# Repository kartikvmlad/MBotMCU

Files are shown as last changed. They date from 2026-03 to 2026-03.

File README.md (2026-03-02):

# Astra Robotics Controller (ARC-2040)

  

**A high-performance embedded control board designed for autonomous mobile robotics.**

The **Astra Robotics Controller** bridges the gap between prototyping boards and industrial PLCs. Built around the Raspberry Pi **RP2040** microcontroller, it integrates high-current motor drivers, redundant sensing, and non-volatile "Black Box" data logging into a unified, vibration-resistant PCB.

-> To view the schematic, download the repository and open the file **MBot.kicad_sch** in KiCad 

---

## 📋 Table of Contents
- [System Architecture](#-system-architecture)
- [Technical Specifications](#-technical-specifications)
- [Pin Configuration](#-pin-configuration)
- [Power System & Safety](#-power-system--safety)
- [Fabrication Notes](#-fabrication-notes-bom-criticals)
- [Getting Started](#-getting-started)

---

## 🏗 System Architecture

The board is divided into four isolated subsystems to minimize noise and maximize reliability:

1.  **Core Logic:** RP2040 Dual-Core Cortex-M0+ running at 133MHz with 2MB QSPI Flash.
2.  **Actuation:** Dual **DRV8876** H-Bridge drivers capable of 5A peak current, featuring hardware current regulation and fault feedback.
3.  **Sensing:**
    * **Motion:** InvenSense **MPU-9150** (9-DoF IMU) for heading and stabilization.
    * **Environment:** Bosch **BMP280** for barometric altitude and temperature.
    * **Data Logging:** Cypress **FM24W256 F-RAM** for high-speed, infinite-endurance telemetry logging.
4.  **Power:** A hybrid 12V $\to$ 6.5V $\to$ 5V/3.3V power tree using a high-efficiency **XL4015** Buck Converter.

---

## ⚙ Technical Specifications

| Feature | Specification |
| :--- | :--- |
| **Microcontroller** | Raspberry Pi RP2040 (Dual Core ARM M0+ @ 133MHz) |
| **Input Voltage** | 10V - 14V DC (Optimized for 3S LiPo or 12V Lead Acid) |
| **Motor Drive Output** | 2x Channels, 6.5V Regulated @ 3A Continuous / 5A Peak |
| **Logic Voltage** | 3.3V (System) / 5.0V (Auxiliary) |
| **IMU** | MPU-9150 (Gyro + Accel + Mag) via I2C `0x68` |
| **Altimeter** | BMP280 via I2C `0x76` |
| **Non-Volatile Memory** | 256 Kbit (32KB) Ferroelectric RAM via I2C `0x50` |
| **Expansion** | 4x ADC, 2x UART, 1x I2C, 1x SPI |

---

## 📍 Pin Configuration

### External Interfaces
| Port Label | Function | Pinout | Voltage Level |
| :--- | :--- | :--- | :--- |
| **J1 (SWD)** | Firmware Debugging | SWDIO, SWCLK, GND | 3.3V |
| **J3 (ADC)** | Analog Sensors | ADC0-2, 3V3, AGND | 3.3V |
| **J7 (UART0)** | GPS / Lidar | TX, RX, 3V3, GND | 3.3V |
| **J8 (I2C)** | Expansion / OLED | SDA, SCL, 3V3, GND | 3.3V |
| **J14 (PWM)** | Servo / GPIO | PWM_A, PWM_B, 3V3, GND | 3.3V |

### Onboard Switch Multiplexer
The board features hardware toggle switches to route the RP2040 ADC lines:
* **Position A (Left):** ADC monitors **Motor Current** (via DRV8876 IPROPI).
* **Position B (Right):** ADC monitors **External Sensors** (via Port J3).

---

## ⚡ Power System & Safety

This board implements a **Split-Rail Architecture**:
* **VMOT (6.5V Rail):** Powered by an XL4015 Buck Converter. Dedicated to Motors and High-Torque Servos.
* **VSYS (5.0V Rail):** Powered by an AMS1117-5.0. Dedicated to logic-level conversion.
* **3V3 (Logic Rail):** Powered by onboard LDO for MCU and Sensors.

**Safety Features:**
* **Reverse Polarity Protection:** 5A Schottky Diodes on input.
* **Over-Current Protection:** On-board Fuse (F1) and software-readable Current Sense.
* **Thermal Protection:** DRV8876 drivers have automatic thermal shutdown with LED indication (`nFAULT`).

> **⚠️ Usage Warning:** Port `J8`, `J9`, and `J10` (Motor/Aux) supply **6.5V** on Pin 3. Do not connect standard 5V-intolerant logic devices to this pin without checking datasheets.

---

## 🛠 Fabrication Notes (BOM Criticals)

If fabricating this board from the provided Gerbers, strictly adhere to the following component requirements to ensure power stability:

1.  **Diodes (D4, D5, D6):** MUST be **SS54** (5 Amp) or **MBRD1045** (10 Amp). Using SS34 (3A) may result in thermal failure under load.
2.  **Inductor (L1):** Footprint requires a **Shielded Power Inductor** (e.g., CDRH127) rated for **Isat > 5A**.
3.  **Capacitors:**
    * **Cout1:** 330µF/25V Electrolytic Low-ESR is mandatory for 6.5V rail stability.

---

## 🚀 Getting Started

1.  **Hardware Setup:**
    * Connect a 12V battery to the Screw Terminal (J3) or Barrel Jack (J2).
    * Connect motors to the JST outputs `M0` and `M1`.
2.  **Firmware Upload:**
    * Hold the **BOOT** button (or short `BOOTSEL` jumper).
    * Connect USB-C to a PC.
    * Copy your `.uf2` file to the `RPI-RP2` drive.
3.  **Software Addresses:**
    * `BMP280`: **0x76**
    * `MPU9150`: **0x68**
    * `FRAM`: **0x50**

---

**Project Lead:** Kartik Lad  
**Organization:** Astra Robotics  
**License:** Open Source Hardware

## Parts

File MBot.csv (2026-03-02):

Reference | Qty | Value | Cost (per piece) | Total Comp cost | Site | Link to buy | Footprint | Datasheet
C1,C14,C101,C104,C117 | 5 | 10u | ? 1.34 | ? 6.70 | Robu | https://robu.in/product/0805x106k250nt-fh-25v-10uf-x5r%c2%b110-0805-multilayer-ceramic-capacitors-mlcc-smd-smt-rohs/ | Capacitor_SMD:C_0805_2012Metric_Pad1.18x1.45mm_HandSolder | ~
C2,C5,C7 | 3 | 22n | ? 0.68 | ? 2.04 | Robu | https://robu.in/product/22nf-0603-surface-mount-multilayer-ceramic-capacitor-pack-of-50/ | Capacitor_SMD:C_0603_1608Metric_Pad1.08x0.95mm_HandSolder | ~
C3,C4,C6,C13 | 4 | 220n | ? 0.60 | ? 2.40 | Robu | https://robu.in/product/220nf-0603-surface-mount-multilayer-ceramic-capacitor-pack-of-40/ | Capacitor_SMD:C_0603_1608Metric_Pad1.08x0.95mm_HandSolder | ~
C8,C22,C23 | 3 | 10n | ? 0.63 | ? 1.89 | Robu | https://robu.in/product/10nf-0603-surface-mount-multilayer-ceramic-capacitor-pack-of-50/ | Capacitor_SMD:C_0603_1608Metric_Pad1.08x0.95mm_HandSolder | ~
C9,C10,C11,C15,C16,C18,C19,C20,C105,C106,C107,C109,C110,C111,C112,C113,C114,C115,C120 | 19 | 100n | ? 0.30 | ? 5.70 | Robu | https://robu.in/product/100nf-0603-surface-mount-multilayer-ceramic-capacitor-pack-of-40/ | Capacitor_SMD:C_0603_1608Metric_Pad1.08x0.95mm_HandSolder | ~
C12 | 1 | 2.2n | ? 0.42 | ? 0.42 | Robu | https://robu.in/product/2-2nf-0603-surface-mount-multilayer-ceramic-capacitor-pack-of-50/ | Capacitor_SMD:C_0603_1608Metric_Pad1.08x0.95mm_HandSolder | ~
C17 | 1 | 100u |  | ? 0.00 |  |  | Capacitor_SMD:C_0805_2012Metric_Pad1.18x1.45mm_HandSolder | ~
C21,C108 | 2 | 1u | ? 0.55 | ? 1.10 | Robu | https://robu.in/product/0603b105k160nt-fh-16v-1uf-x7r%c2%b110-0603-multilayer-ceramic-capacitors-mlcc-smd-smt-rohs/ | Capacitor_SMD:C_0603_1608Metric_Pad1.08x0.95mm_HandSolder | ~
C102,C103 | 2 | 15p | ? 0.24 | ? 0.48 | Robu | https://robu.in/product/ac0603jrnpo9bn150-yageo-cap-ceramic-15pf-50v-c0g-5-pad-smd-0603-125c-automotive-aec-q200-t-r/ | Capacitor_SMD:C_0603_1608Metric_Pad1.08x0.95mm_HandSolder | ~
CFF1 | 1 | 33n | ? 0.68 | ? 0.68 | Robu | https://robu.in/product/33nf-0603-surface-mount-multilayer-ceramic-capacitor-pack-of-50/ | Capacitor_SMD:C_0603_1608Metric_Pad1.08x0.95mm_HandSolder | ~
Cin1 | 1 | 220u |  | ? 0.00 |  |  | Capacitor_SMD:C_0805_2012Metric_Pad1.18x1.45mm_HandSolder | ~
Cout1,Cout2 | 2 | 22u |  | ? 0.00 |  |  | Capacitor_SMD:C_0805_2012Metric_Pad1.18x1.45mm_HandSolder | ~
D1,D2,D3 | 3 | LED | ? 1.18 | ? 3.54 | Robu | https://robu.in/product/0805-surface-mount-led-red-50-pcs/ | LED_SMD:LED_0805_2012Metric_Pad1.15x1.40mm_HandSolder | ~
D4,D5 | 2 | SS54B | ? 6.00 | ? 12.00 | Robu | https://robu.in/product/ss54b-slkor-40v-550mv5a-5a-smbdo-214aa-schottky-diodes-rohs/ | SS54B:DIOM4336X244N
D6,D7,D8 | 3 | WS2812B-2020 | ? 8.00 | ? 24.00 | Robu | https://robu.in/product/sme-ws2812b-2020-addressable-rgb-pixel-led-worldsemi/ | LED_SMD:LED_WS2812B-2020_PLCC4_2.0x2.0mm | https://cdn-shop.adafruit.com/product-files/4684/4684_WS2812B-2020_V1.3_EN.pdf
D101,D102 | 2 | SS14 | ? 1.35 | ? 2.70 | Robu | https://robu.in/product/ss14-slkor-40v-550mv1a-1a-smado-214ac-schottky-diodes-rohs/ | Diode_SMD:D_SMA_Handsoldering | https://www.vishay.com/docs/88746/ss12.pdf
F1 | 1 | Fuse | ? 33.00 | ? 33.00 | Robu | https://robu.in/product/01550900m-littelfuse-smd5-0x9-7mm-fuseholders-rohs/ | Fuse:Fuse_Littelfuse-NANO2-451_453 | ~
FB1 | 1 | FerriteBead | ? 4.67 | ? 4.67 | Robu | https://robu.in/product/blm21bb201sn1d-murata-ferrite-bead-0805-2012-metric-200-ohm-500-ma-blm21b-0-26-ohm-%c2%b1-25/ | Inductor_SMD:L_0805_2012Metric_Pad1.05x1.20mm_HandSolder | ~
J1 | 1 | Micro_SD_Card_Det1 |  | ? 0.00 |  |  | Connector_Card:microSD_HC_Hirose_DM3AT-SF-PEJM5 | https://datasheet.lcsc.com/lcsc/2110151630_XKB-Connectivity-XKTF-015-N_C381082.pdf
J2 | 1 | Barrel_Jack_Switch_Pin3Ring |  | ? 0.00 |  |  | Connector_BarrelJack:BarrelJack_Horizontal | ~
J3,J5,J6,J7 | 4 | Screw_Terminal_01x02 |  | ? 0.00 |  |  | TerminalBlock_Phoenix:TerminalBlock_Phoenix_MPT-0,5-2-2.54_1x02_P2.54mm_Horizontal | ~
J4 | 1 | Conn_01x03 |  | ? 0.00 |  |  | Connector_JST:JST_VH_B3P-VH_1x03_P3.96mm_Vertical | ~
J8,J9,J10,J12,J13,J14,J15,J17 | 8 | Conn_01x04 |  | ? 0.00 |  |  | Connector_JST:JST_ZH_B4B-ZR_1x04_P1.50mm_Vertical | ~
J11 | 1 | Conn_02x06_Odd_Even |  | ? 0.00 |  |  | Connector_IDC:IDC-Header_2x06_P2.54mm_Vertical | ~
J16 | 1 | Conn_01x06 |  | ? 0.00 |  |  | Connector_JST:JST_ZH_B6B-ZR_1x06_P1.50mm_Vertical | ~
JUSBC1 | 1 | USB_C_Receptacle_USB2.0_16P |  | ? 0.00 |  |  | Connector_USB:USB_C_Receptacle_GCT_USB4085 | https://www.usb.org/sites/default/files/documents/usb_type-c.zip
L1 | 1 | 3.3u | ? 11.00 | ? 11.00 | Robu | https://robu.in/product/srp7050ta-3r3m-bourns-power-inductor-smd-3-3-%c2%b5h-8-a-shielded-12-a/ | Inductor_SMD:L_Bourns_SRP7028A_7.3x6.6mm | ~
R1 | 1 | 100k | ? 1.38 | ? 1.38 | Robu | https://robu.in/product/aa0603jr-07100kl-yageo-100mw-thick-film-resistors-75v-%c2%b15-%c2%b1150ppm-%e2%84%83-100k%cf%89-0603-chip-resistor-surface-mount-rohs/ | Resistor_SMD:R_0603_1608Metric_Pad0.98x0.95mm_HandSolder | ~
R2,R5,R7,R9,R12,R14,R101,R105 | 8 | 1k | ? 0.35 | ? 2.80 | Robu |  | Resistor_SMD:R_0603_1608Metric_Pad0.98x0.95mm_HandSolder | ~
R3,R8,R13,R32,R901 | 5 | 10k | ? 0.35 | ? 1.75 | Robu |  | Resistor_SMD:R_0603_1608Metric_Pad0.98x0.95mm_HandSolder | ~
R4,R11,R16 | 3 | 220 | ? 0.35 | ? 1.05 | Robu |  | Resistor_SMD:R_0603_1608Metric_Pad0.98x0.95mm_HandSolder | ~
R6,R10,R15 | 3 | 20k | ? 0.30 | ? 0.90 | Robu |  | Resistor_SMD:R_0603_1608Metric_Pad0.98x0.95mm_HandSolder | ~
R17,R18,R19 | 3 | 330 | ? 0.46 | ? 1.38 | Robu |  | Resistor_SMD:R_0603_1608Metric_Pad0.98x0.95mm_HandSolder | ~
R23,R24 | 2 | 4.7k | ? 0.35 | ? 0.70 | Robu |  | Resistor_SMD:R_0603_1608Metric_Pad0.98x0.95mm_HandSolder | ~
R27 | 1 | 47k | ? 0.35 | ? 0.35 | Robu |  | Resistor_SMD:R_0603_1608Metric_Pad0.98x0.95mm_HandSolder | ~
R109,RUSB1 | 2 | 5.1k | ? 0.32 | ? 0.64 | Robu |  | Resistor_SMD:R_0603_1608Metric_Pad0.98x0.95mm_HandSolder | ~
R902 | 1 | 75k | ? 0.44 | ? 0.44 | Robu |  | Resistor_SMD:R_0603_1608Metric_Pad0.98x0.95mm_HandSolder | ~
RDminus1,RDplus1 | 2 | 27 | ? 0.82 | ? 1.64 | Robu |  | Resistor_SMD:R_0603_1608Metric_Pad0.98x0.95mm_HandSolder | ~ | 0805 only
SW4,SWRESET1 | 2 | SW_SPST |  | ? 0.00 |  |  | Button_Switch_SMD:SW_Push_SPST_NO_Alps_SKRK | ~
U1 | 1 | 74AUC1G19 | ? 16.00 | ? 16.00 | Robu |  | Package_TO_SOT_SMD:SOT-23-6_Handsoldering | http://www.ti.com/lit/sg/scyt129e/scyt129e.pdf
U2 | 1 | TPS565201DDCR | ? 11.00 | ? 11.00 | Robu |  | TPS565201DDCR:SOT95P280X110-6N |  | sus looking robu
U3 | 1 | FM24W256 | ? 207.00 | ? 207.00 | Robu |  | Package_SO:SOIC-8_3.9x4.9mm_P1.27mm | http://www.cypress.com/file/41651/download
U4 | 1 | TMUX1574PW | ? 37.00 | ? 37.00 | Robu |  | Package_SO:TSSOP-16_4.4x5mm_P0.65mm | https://www.ti.com/lit/ds/symlink/tmux1574.pdf
UBarometer1 | 1 | BMP280 | ? 33.00 | ? 33.00 |  |  | Package_LGA:Bosch_LGA-8_2x2.5mm_P0.65mm_ClockwisePinNumbering | https://ae-bst.resource.bosch.com/media/_tech/media/datasheets/BST-BMP280-DS001.pdf | header pins needed
UDRV1,UDRV2,UDRV3 | 3 | DRV8876PWPR | ? 189.00 | ? 567.00 | Lion Ckt | https://www.lioncircuits.com/parts/DRV8876PWPR | DRV8876PWPR:IC_DRV8876PWPR
UESD1 | 1 | USBLC6-2SC6 | ? 6.00 | ? 6.00 | Robu |  | Package_TO_SOT_SMD:SOT-23-6 | https://www.st.com/resource/en/datasheet/usblc6-2.pdf
UFlashMem1 | 1 | W25Q16JVSS | ? 51.00 | ? 51.00 | Robu |  | Package_SO:SOIC-8_5.3x5.3mm_P1.27mm | https://www.winbond.com/hq/support/documentation/levelOne.jsp?__locale=en&DocNo=DA00-W25Q16JV.1
UIMU1 | 1 | MPU-9150 |  | ? 0.00 | Robu |  | Sensor_Motion:InvenSense_QFN-24_4x4mm_P0.5mm | https://www.invensense.com/wp-content/uploads/2015/02/MPU-9150-Datasheet.pdf
ULDO1 | 1 | NCP1117-3.3_SOT223 | ? 23.00 | ? 23.00 | Robu |  | Package_TO_SOT_SMD:SOT-223-3_TabPin2 | http://www.onsemi.com/pub_link/Collateral/NCP1117-D.PDF
URP2040 | 1 | RP2040 | ? 80.00 | ? 80.00 | Robu |  | Package_DFN_QFN:QFN-56-1EP_7x7mm_P0.4mm_EP3.2x3.2mm | https://datasheets.raspberrypi.com/rp2040/rp2040-datasheet.pdf
YCrystalOscillator1 | 1 | ABM8-272-T3 | ? 65.00 | ? 65.00 | Robu |  | ABM8-272-T3:XTAL_ABM8-272-T3
 |  |  |  | ? 1,221.35

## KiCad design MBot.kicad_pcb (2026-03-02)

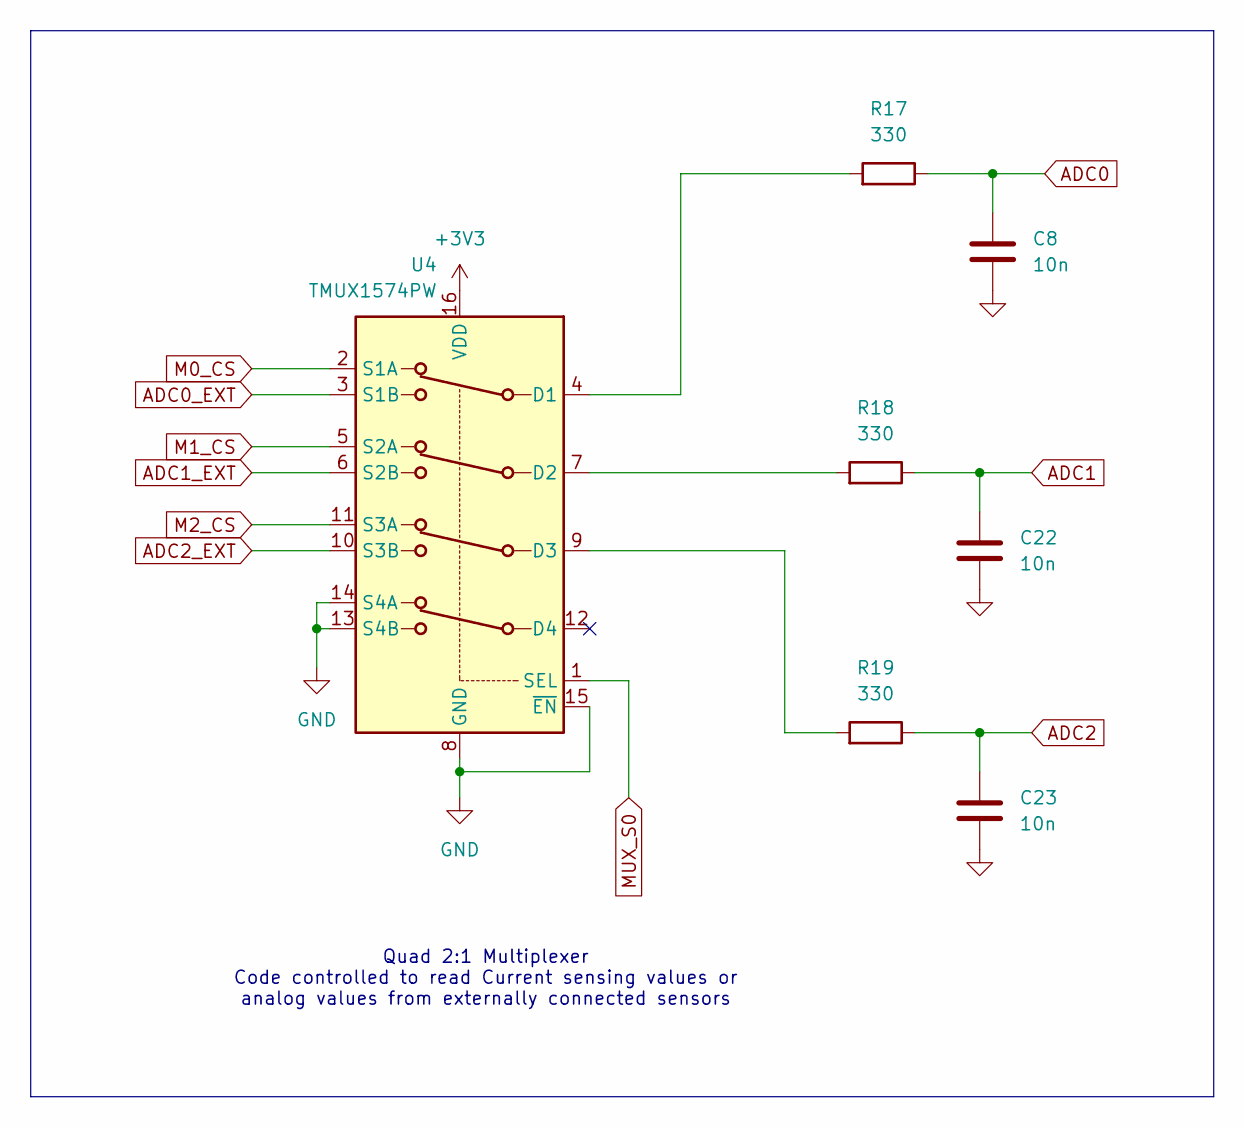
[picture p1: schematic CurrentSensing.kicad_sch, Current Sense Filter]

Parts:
C8, C22, C23: 10n; C_0603_1608Metric_Pad1.08x0.95mm_HandSolder
R17, R18, R19: 330; R_0603_1608Metric_Pad0.98x0.95mm_HandSolder
U4: TMUX1574PW; TSSOP-16_4.4x5mm_P0.65mm

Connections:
+3V3: U4.16 (VDD); also elsewhere on the board
ADC0: C8.1, R17.1; also elsewhere on the board
ADC0_EXT: U4.3 (S1B); also elsewhere on the board
ADC1: C22.1, R18.1; also elsewhere on the board
ADC1_EXT: U4.6 (S2B); also elsewhere on the board
ADC2: C23.1, R19.1; also elsewhere on the board
ADC2_EXT: U4.10 (S3B); also elsewhere on the board
GND: C8.2, C22.2, C23.2, U4.8 (GND), U4.13 (S4B), U4.14 (S4A), U4.15 (~EN); also elsewhere on the board
M0_CS: U4.2 (S1A); also elsewhere on the board
M1_CS: U4.5 (S2A); also elsewhere on the board
M2_CS: U4.11 (S3A); also elsewhere on the board
MUX_S0: U4.1 (SEL); also elsewhere on the board
unnamed: R17.2, U4.4 (D1)
unnamed: R18.2, U4.7 (D2)
unnamed: R19.2, U4.9 (D3)

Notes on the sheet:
Quad 2:1 Multiplexer Code controlled to read Current sensing values or analog values from externally connected sensors

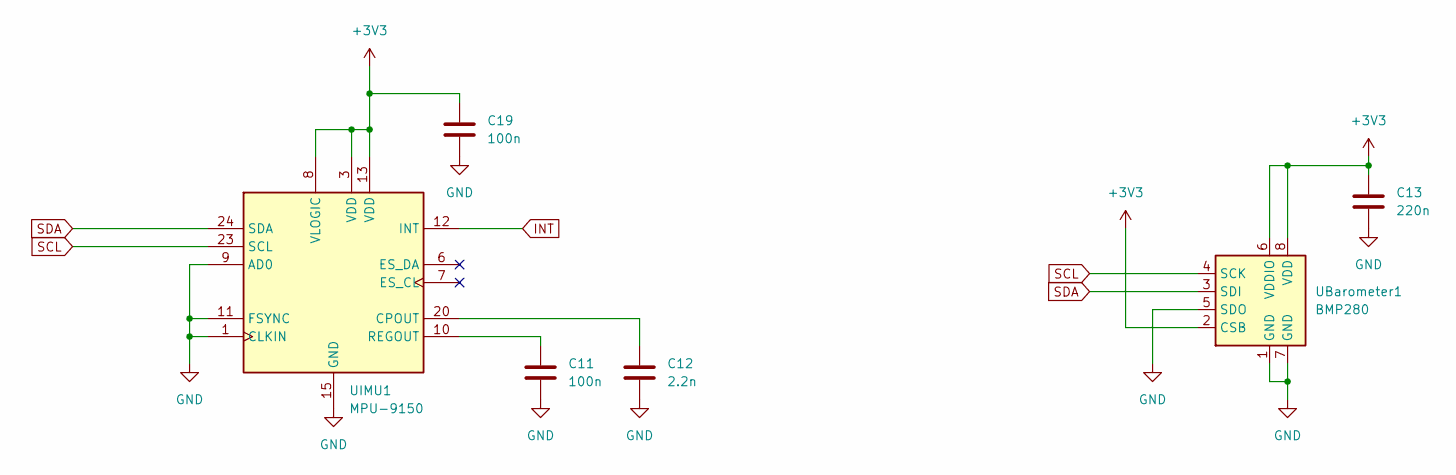
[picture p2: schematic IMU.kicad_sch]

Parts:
C11, C19: 100n; C_0603_1608Metric_Pad1.08x0.95mm_HandSolder
C12: 2.2n; C_0603_1608Metric_Pad1.08x0.95mm_HandSolder
C13: 220n; C_0603_1608Metric_Pad1.08x0.95mm_HandSolder
UBarometer1: BMP280; Bosch_LGA-8_2x2.5mm_P0.65mm_ClockwisePinNumbering
UIMU1: MPU-9150; InvenSense_QFN-24_4x4mm_P0.5mm

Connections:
+3V3: C13.1, C19.1, UBarometer1.2 (CSB), UBarometer1.6 (VDDIO), UBarometer1.8 (VDD), UIMU1.3 (VDD), UIMU1.8 (VLOGIC), UIMU1.13 (VDD); also elsewhere on the board
GND: C11.2, C12.2, C13.2, C19.2, UBarometer1.1 (GND), UBarometer1.5 (SDO), UBarometer1.7 (GND), UIMU1.1 (CLKIN), UIMU1.9 (AD0), UIMU1.11 (FSYNC), UIMU1.15 (GND), UIMU1.17 (GND), UIMU1.18 (GND); also elsewhere on the board
INT: UIMU1.12 (INT); also elsewhere on the board
unnamed: C12.1, UIMU1.20 (CPOUT)
unnamed: C11.1, UIMU1.10 (REGOUT)
SCL: UBarometer1.4 (SCK), UIMU1.23 (SCL); also elsewhere on the board
SDA: UBarometer1.3 (SDI), UIMU1.24 (SDA); also elsewhere on the board

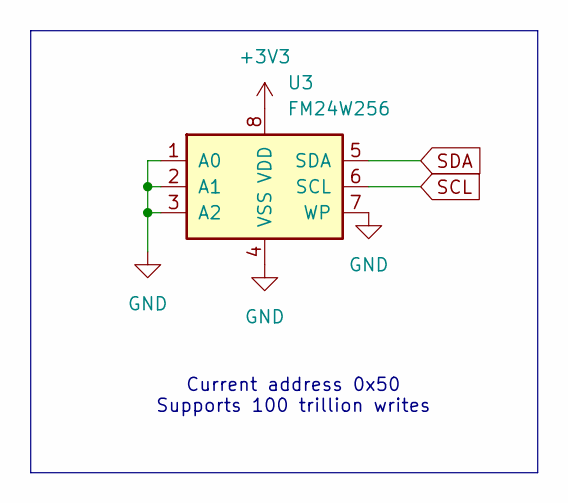
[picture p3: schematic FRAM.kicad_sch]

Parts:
U3: FM24W256; SOIC-8_3.9x4.9mm_P1.27mm

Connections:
+3V3: U3.8 (VDD); also elsewhere on the board
GND: U3.1 (A0), U3.2 (A1), U3.3 (A2), U3.4 (VSS), U3.7 (WP); also elsewhere on the board
SCL: U3.6 (SCL); also elsewhere on the board
SDA: U3.5 (SDA); also elsewhere on the board

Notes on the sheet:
Current address 0x50 Supports 100 trillion writes

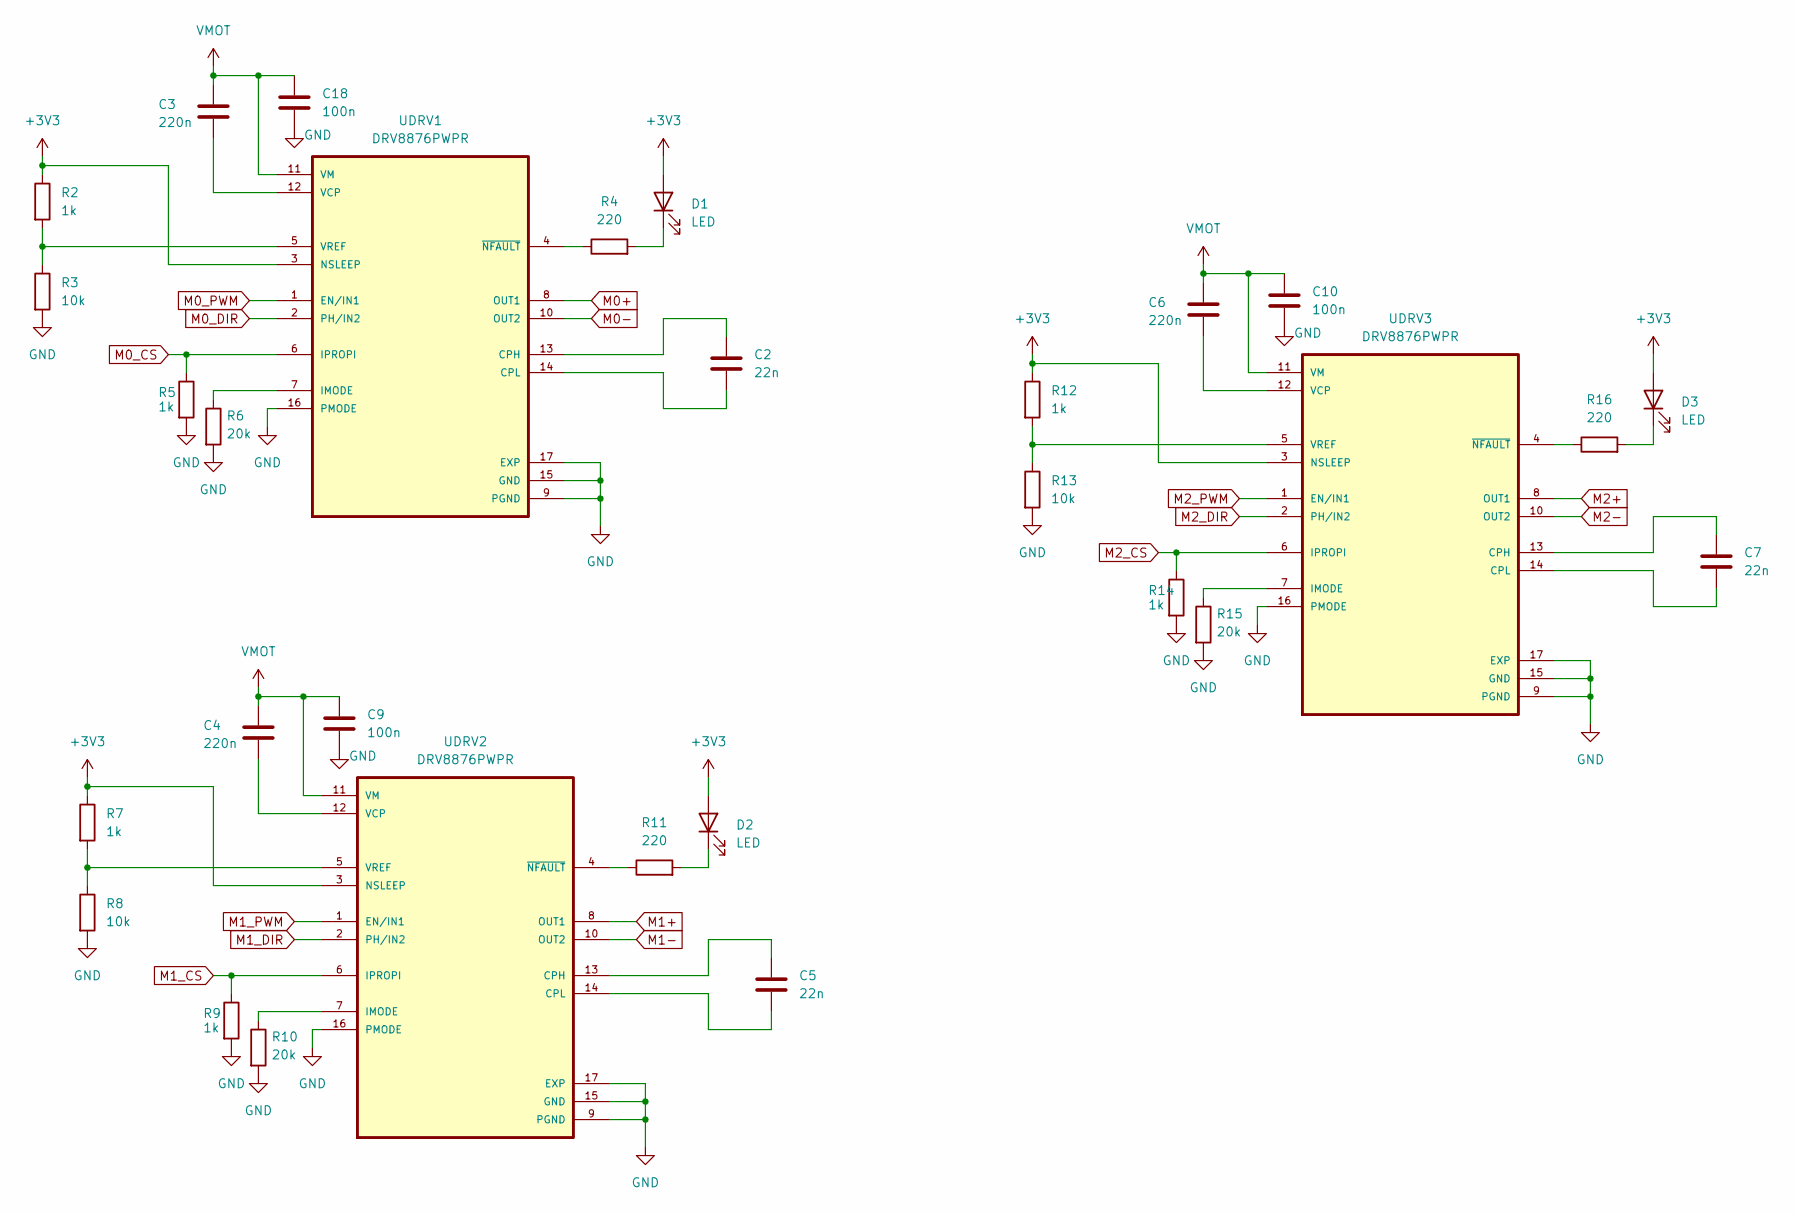
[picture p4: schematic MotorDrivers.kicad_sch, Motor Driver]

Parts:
C2, C5, C7: 22n; C_0603_1608Metric_Pad1.08x0.95mm_HandSolder
C3, C4, C6: 220n; C_0603_1608Metric_Pad1.08x0.95mm_HandSolder
C9, C10, C18: 100n; C_0603_1608Metric_Pad1.08x0.95mm_HandSolder
D1, D2, D3: LED; LED_0805_2012Metric_Pad1.15x1.40mm_HandSolder
R2, R5, R7, R9, R12, R14: 1k; R_0603_1608Metric_Pad0.98x0.95mm_HandSolder
R3, R8, R13: 10k; R_0603_1608Metric_Pad0.98x0.95mm_HandSolder
R4, R11, R16: 220; R_0603_1608Metric_Pad0.98x0.95mm_HandSolder
R6, R10, R15: 20k; R_0603_1608Metric_Pad0.98x0.95mm_HandSolder
UDRV1, UDRV2, UDRV3: DRV8876PWPR; IC_DRV8876PWPR; PARTREV E

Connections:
+3V3: D1.2 (A), D2.2 (A), D3.2 (A), R2.1, R7.1, R12.1, UDRV1.3 (NSLEEP), UDRV2.3 (NSLEEP), UDRV3.3 (NSLEEP); also elsewhere on the board
GND: C9.2, C10.2, C18.2, R3.2, R5.2, R6.2, R8.2, R9.2, R10.2, R13.2, R14.2, R15.2, UDRV1.9 (PGND), UDRV1.15 (GND), UDRV1.16 (PMODE), UDRV1.17 (EXP), UDRV2.9 (PGND), UDRV2.15 (GND), UDRV2.16 (PMODE), UDRV2.17 (EXP), UDRV3.9 (PGND), UDRV3.15 (GND), UDRV3.16 (PMODE), UDRV3.17 (EXP); also elsewhere on the board
M0+: UDRV1.8 (OUT1); also elsewhere on the board
M0-: UDRV1.10 (OUT2); also elsewhere on the board
M0_CS: R5.1, UDRV1.6 (IPROPI); also elsewhere on the board
M0_DIR: UDRV1.2 (PH/IN2); also elsewhere on the board
M0_PWM: UDRV1.1 (EN/IN1); also elsewhere on the board
M1+: UDRV2.8 (OUT1); also elsewhere on the board
M1-: UDRV2.10 (OUT2); also elsewhere on the board
M1_CS: R9.1, UDRV2.6 (IPROPI); also elsewhere on the board
M1_DIR: UDRV2.2 (PH/IN2); also elsewhere on the board
M1_PWM: UDRV2.1 (EN/IN1); also elsewhere on the board
M2+: UDRV3.8 (OUT1); also elsewhere on the board
M2-: UDRV3.10 (OUT2); also elsewhere on the board
M2_CS: R14.1, UDRV3.6 (IPROPI); also elsewhere on the board
M2_DIR: UDRV3.2 (PH/IN2); also elsewhere on the board
M2_PWM: UDRV3.1 (EN/IN1); also elsewhere on the board
unnamed: D1.1 (K), R4.2
unnamed: D2.1 (K), R11.2
unnamed: D3.1 (K), R16.2
unnamed: C2.1, UDRV1.13 (CPH)
unnamed: C2.2, UDRV1.14 (CPL)
unnamed: R6.1, UDRV1.7 (IMODE)
unnamed: C3.2, UDRV1.12 (VCP)
unnamed: R2.2, R3.1, UDRV1.5 (VREF)
unnamed: R4.1, UDRV1.4 (~NFAULT)
unnamed: C5.1, UDRV2.13 (CPH)
unnamed: C5.2, UDRV2.14 (CPL)
unnamed: R10.1, UDRV2.7 (IMODE)
unnamed: C4.2, UDRV2.12 (VCP)
unnamed: R7.2, R8.1, UDRV2.5 (VREF)
unnamed: R11.1, UDRV2.4 (~NFAULT)
unnamed: C7.1, UDRV3.13 (CPH)
unnamed: C7.2, UDRV3.14 (CPL)
unnamed: R15.1, UDRV3.7 (IMODE)
unnamed: C6.2, UDRV3.12 (VCP)
unnamed: R12.2, R13.1, UDRV3.5 (VREF)
unnamed: R16.1, UDRV3.4 (~NFAULT)
VMOT: C3.1, C4.1, C6.1, C9.1, C10.1, C18.1, UDRV1.11 (VM), UDRV2.11 (VM), UDRV3.11 (VM); also elsewhere on the board

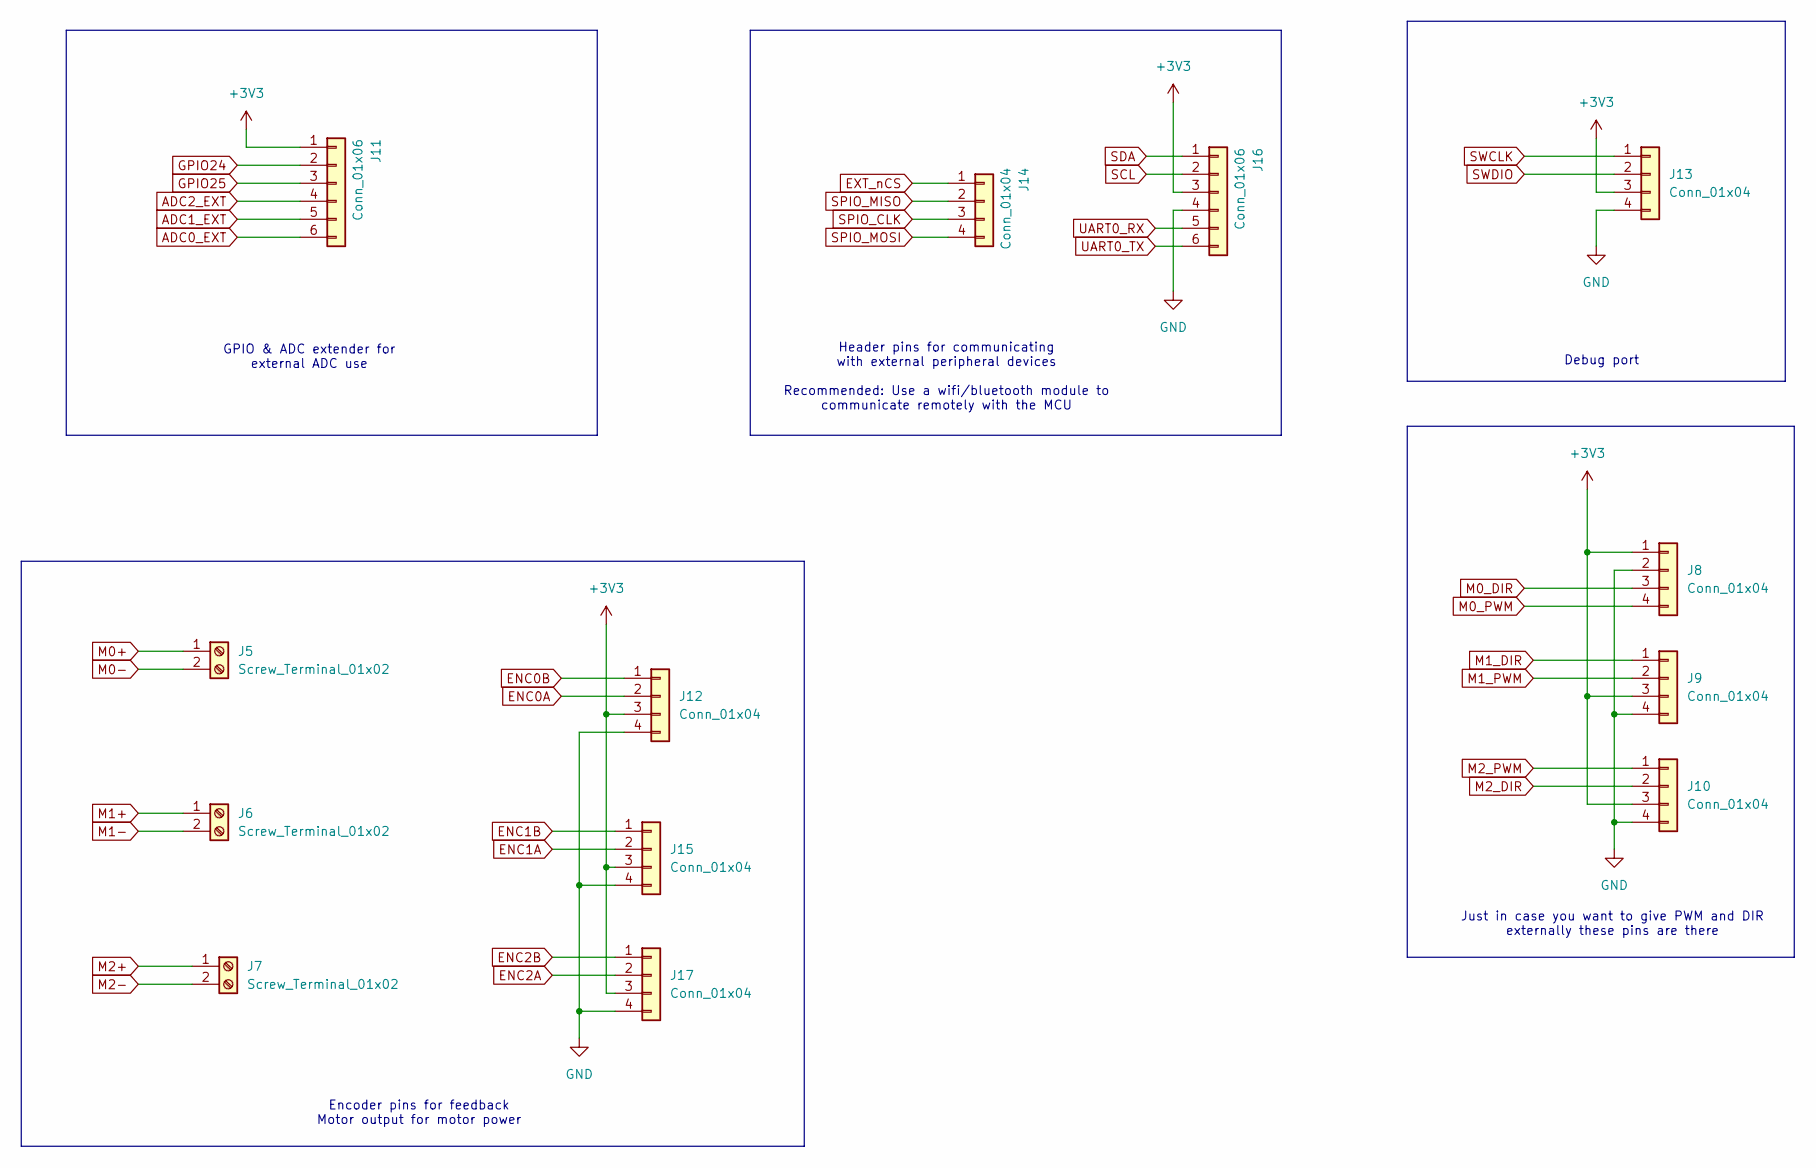
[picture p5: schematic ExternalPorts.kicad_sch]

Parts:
J5, J6, J7: Screw_Terminal_01x02; TerminalBlock_Phoenix_MPT-0,5-2-2.54_1x02_P2.54mm_Horizontal
J8, J9, J10, J12, J13, J14, J15, J17: Conn_01x04; JST_ZH_B4B-ZR_1x04_P1.50mm_Vertical
J11, J16: Conn_01x06; JST_ZH_B6B-ZR_1x06_P1.50mm_Vertical

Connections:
+3V3: J8.1, J9.3, J10.3, J11.1, J12.3, J13.3, J15.3, J16.3, J17.3; also elsewhere on the board
ADC0_EXT: J11.6; also elsewhere on the board
ADC1_EXT: J11.5; also elsewhere on the board
ADC2_EXT: J11.4; also elsewhere on the board
ENC0A: J12.2; also elsewhere on the board
ENC0B: J12.1; also elsewhere on the board
ENC1A: J15.2; also elsewhere on the board
ENC1B: J15.1; also elsewhere on the board
ENC2A: J17.2; also elsewhere on the board
ENC2B: J17.1; also elsewhere on the board
EXT_nCS: J14.1; also elsewhere on the board
GND: J8.2, J9.4, J10.4, J12.4, J13.4, J15.4, J16.4, J17.4; also elsewhere on the board
GPIO24: J11.2; also elsewhere on the board
GPIO25: J11.3; also elsewhere on the board
M0+: J5.1; also elsewhere on the board
M0-: J5.2; also elsewhere on the board
M0_DIR: J8.3; also elsewhere on the board
M0_PWM: J8.4; also elsewhere on the board
M1+: J6.1; also elsewhere on the board
M1-: J6.2; also elsewhere on the board
M1_DIR: J9.1; also elsewhere on the board
M1_PWM: J9.2; also elsewhere on the board
M2+: J7.1; also elsewhere on the board
M2-: J7.2; also elsewhere on the board
M2_DIR: J10.2; also elsewhere on the board
M2_PWM: J10.1; also elsewhere on the board
SCL: J16.2; also elsewhere on the board
SDA: J16.1; also elsewhere on the board
SPIO_CLK: J14.3; also elsewhere on the board
SPIO_MISO: J14.2; also elsewhere on the board
SPIO_MOSI: J14.4; also elsewhere on the board
SWCLK: J13.1; also elsewhere on the board
SWDIO: J13.2; also elsewhere on the board
UART0_RX: J16.5; also elsewhere on the board
UART0_TX: J16.6; also elsewhere on the board

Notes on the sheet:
GPIO & ADC extender for external ADC use
Debug port
Just in case you want to give PWM and DIR externally these pins are there
Header pins for communicating with external peripheral devices Recommended: Use a wifi/bluetooth module to communicate remotely with the MCU
Encoder pins for feedback Motor output for motor power

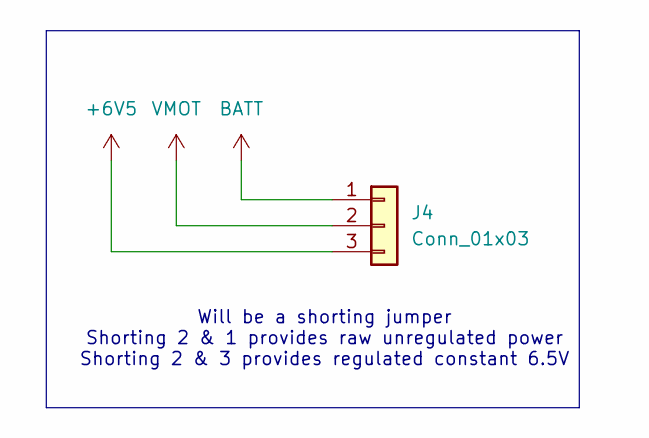
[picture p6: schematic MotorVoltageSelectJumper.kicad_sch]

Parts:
J4: Conn_01x03; JST_VH_B3P-VH_1x03_P3.96mm_Vertical

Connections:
+6V5: J4.3; also elsewhere on the board
BATT: J4.1; also elsewhere on the board
VMOT: J4.2; also elsewhere on the board

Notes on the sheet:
Will be a shorting jumper Shorting 2 & 1 provides raw unregulated power Shorting 2 & 3 provides regulated constant 6.5V

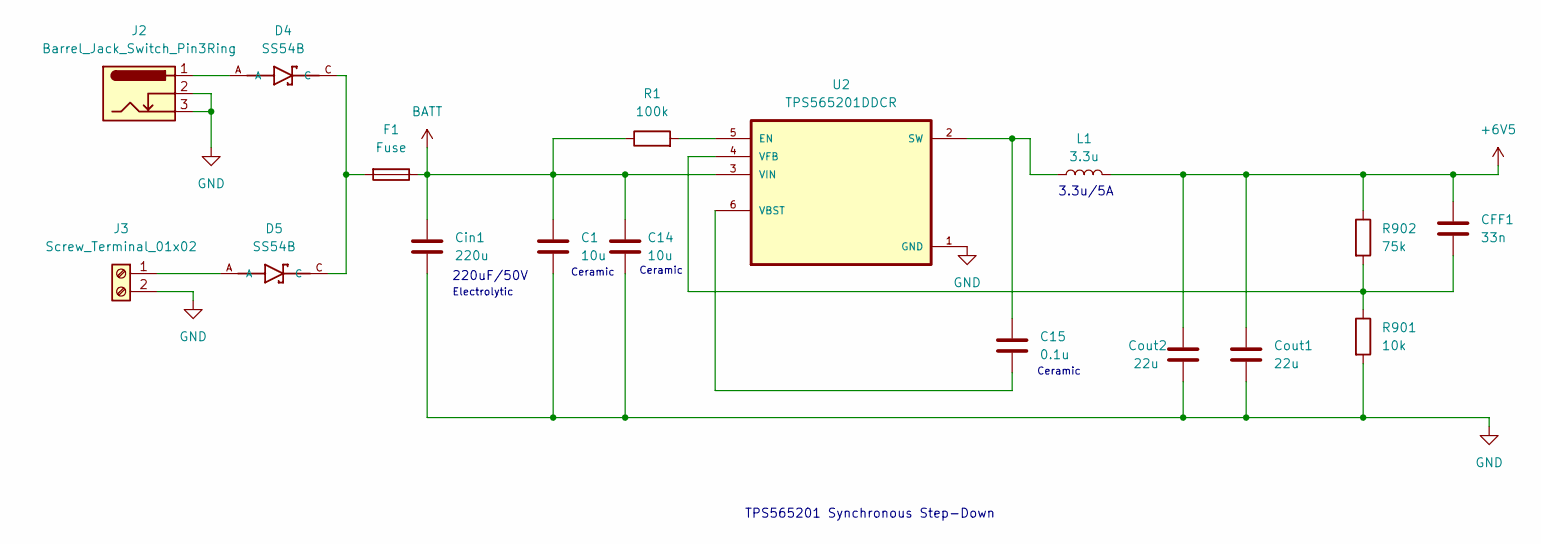
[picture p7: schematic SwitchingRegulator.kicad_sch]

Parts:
C1, C14: 10u; C_0805_2012Metric_Pad1.18x1.45mm_HandSolder
C15: 0.1u; C_0603_1608Metric_Pad1.08x0.95mm_HandSolder
CFF1: 33n; C_0603_1608Metric_Pad1.08x0.95mm_HandSolder
Cin1: 220u; C_0805_2012Metric_Pad1.18x1.45mm_HandSolder
Cout1, Cout2: 22u; C_0805_2012Metric_Pad1.18x1.45mm_HandSolder
D4, D5: SS54B; DIOM4336X244N
F1: Fuse; Fuse_Littelfuse-NANO2-451_453
J2: Barrel_Jack_Switch_Pin3Ring; BarrelJack_Horizontal
J3: Screw_Terminal_01x02; TerminalBlock_Phoenix_MPT-0,5-2-2.54_1x02_P2.54mm_Horizontal
L1: 3.3u; L_Bourns_SRP7028A_7.3x6.6mm
R1: 100k; R_0603_1608Metric_Pad0.98x0.95mm_HandSolder
R901: 10k; R_0603_1608Metric_Pad0.98x0.95mm_HandSolder
R902: 75k; R_0603_1608Metric_Pad0.98x0.95mm_HandSolder
U2: TPS565201DDCR; SOT95P280X110-6N

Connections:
+6V5: CFF1.1, Cout1.1, Cout2.1, L1.2, R902.1; also elsewhere on the board
BATT: C1.1, C14.1, Cin1.1, F1.1, R1.1, U2.3 (VIN); also elsewhere on the board
GND: C1.2, C14.2, Cin1.2, Cout1.2, Cout2.2, J2.2, J2.3, J3.2, R901.2, U2.1 (GND); also elsewhere on the board
unnamed: D4.A, J2.1
unnamed: D4.C, D5.C, F1.2
unnamed: D5.A, J3.1
unnamed: R1.2, U2.5 (EN)
unnamed: C15.1, L1.1, U2.2 (SW)
unnamed: C15.2, U2.6 (VBST)
unnamed: CFF1.2, R901.1, R902.2, U2.4 (VFB)

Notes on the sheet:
Ceramic
TPS565201 Synchronous Step-Down
220uF/50V
Electrolytic
3.3u/5A

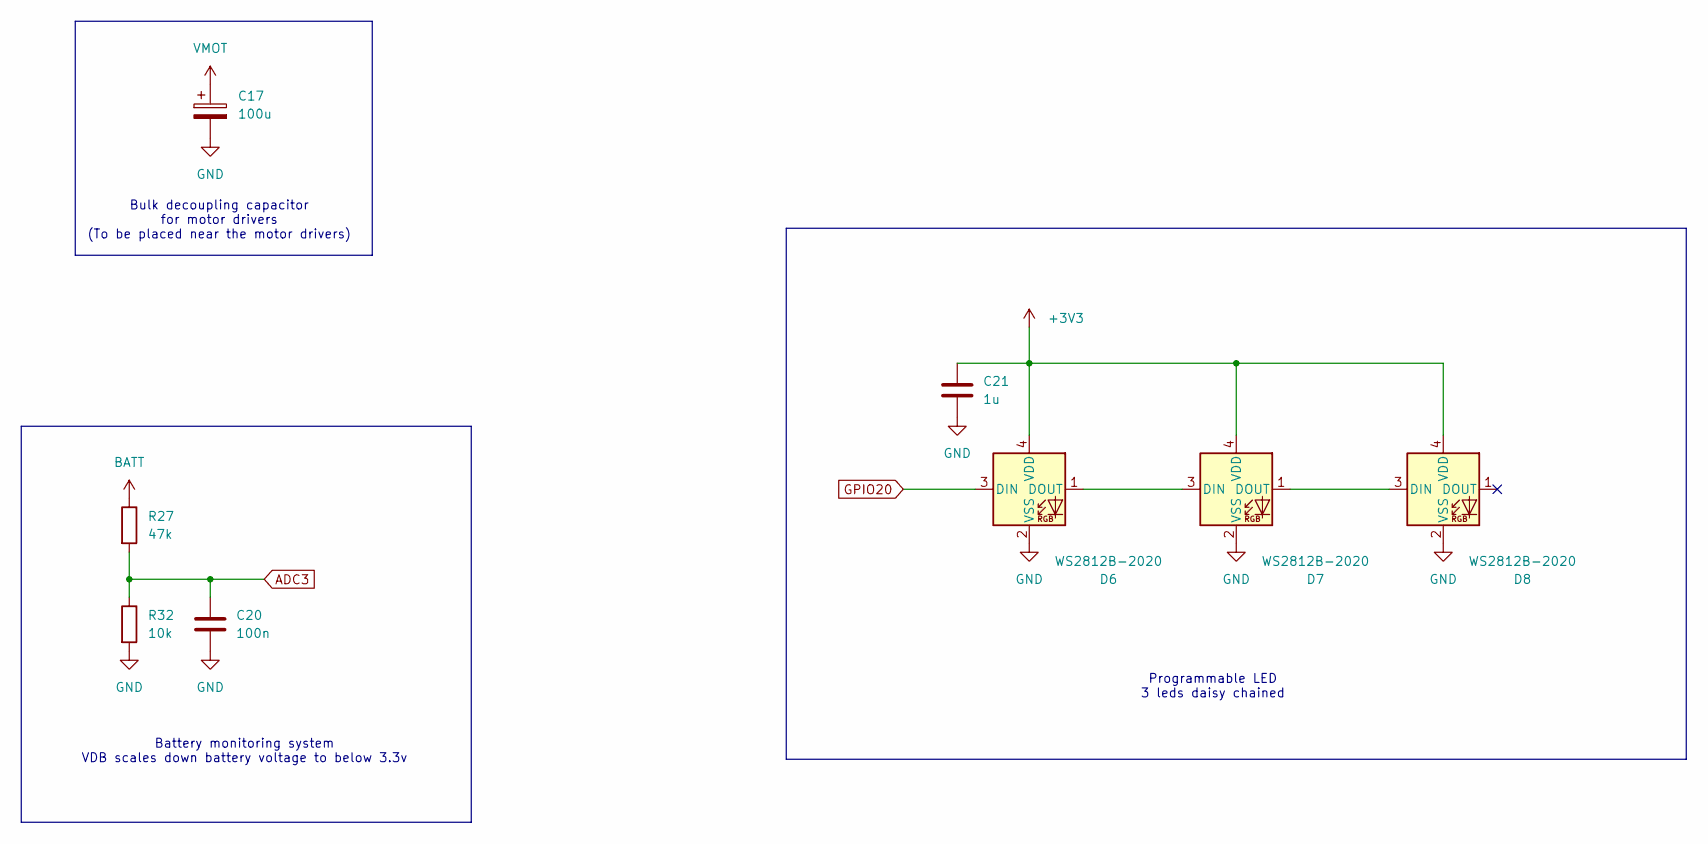
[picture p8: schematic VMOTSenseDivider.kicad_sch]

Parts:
C17: 100u; C_0805_2012Metric_Pad1.18x1.45mm_HandSolder
C20: 100n; C_0603_1608Metric_Pad1.08x0.95mm_HandSolder
C21: 1u; C_0603_1608Metric_Pad1.08x0.95mm_HandSolder
D6, D7, D8: WS2812B-2020; LED_WS2812B-2020_PLCC4_2.0x2.0mm
R27: 47k; R_0603_1608Metric_Pad0.98x0.95mm_HandSolder
R32: 10k; R_0603_1608Metric_Pad0.98x0.95mm_HandSolder

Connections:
+3V3: C21.1, D6.4 (VDD), D7.4 (VDD), D8.4 (VDD); also elsewhere on the board
ADC3: C20.1, R27.2, R32.1; also elsewhere on the board
BATT: R27.1; also elsewhere on the board
GND: C17.2, C20.2, C21.2, D6.2 (VSS), D7.2 (VSS), D8.2 (VSS), R32.2; also elsewhere on the board
GPIO20: D6.3 (DIN); also elsewhere on the board
unnamed: D6.1 (DOUT), D7.3 (DIN)
unnamed: D7.1 (DOUT), D8.3 (DIN)
VMOT: C17.1; also elsewhere on the board

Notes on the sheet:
Battery monitoring system VDB scales down battery voltage to below 3.3v
Bulk decoupling capacitor for motor drivers (To be placed near the motor drivers)
Programmable LED 3 leds daisy chained

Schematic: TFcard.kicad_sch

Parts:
J1: Micro_SD_Card_Det1; microSD_HC_Hirose_DM3AT-SF-PEJM5
U1: 74AUC1G19; SOT-23-6_Handsoldering

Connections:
+3V3: J1.4 (VDD), U1.5 (VCC); also elsewhere on the board
EXT_nCS: U1.6 (Y0); also elsewhere on the board
EXT/SD: U1.1 (A); also elsewhere on the board
GND: J1.6 (VSS), J1.10 (SHIELD), U1.2 (GND); also elsewhere on the board
SD_nCS: J1.2 (DAT3/CD), U1.4 (Y1)
SPIO_CLK: J1.5 (CLK); also elsewhere on the board
SPIO_CS: U1.3 (~E); also elsewhere on the board
SPIO_MISO: J1.7 (DAT0); also elsewhere on the board
SPIO_MOSI: J1.3 (CMD); also elsewhere on the board

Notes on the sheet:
DET is for physical detection of card

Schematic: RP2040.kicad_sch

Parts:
C16, C105, C106, C107, C109, C110, C111, C112, C113, C114, C115, C120: 100n; C_0603_1608Metric_Pad1.08x0.95mm_HandSolder
C101, C104, C117: 10u; C_0805_2012Metric_Pad1.18x1.45mm_HandSolder
C102, C103: 15p; C_0603_1608Metric_Pad1.08x0.95mm_HandSolder
C108: 1u; C_0603_1608Metric_Pad1.08x0.95mm_HandSolder
D101, D102: SS14; D_SMA_Handsoldering
FB1: FerriteBead; L_0805_2012Metric_Pad1.05x1.20mm_HandSolder
JUSBC1: USB_C_Receptacle_USB2.0_16P; USB_C_Receptacle_GCT_USB4085
R23, R24: 4.7k; R_0603_1608Metric_Pad0.98x0.95mm_HandSolder
R101, R105: 1k; R_0603_1608Metric_Pad0.98x0.95mm_HandSolder
R109: 5.1k; R_0603_1608Metric_Pad0.98x0.95mm_HandSolder
RDminus1: 27; R_0603_1608Metric_Pad0.98x0.95mm_HandSolder
RDplus1: 27; R_0603_1608Metric_Pad0.98x0.95mm_HandSolder
RUSB1: 5.1k; R_0603_1608Metric_Pad0.98x0.95mm_HandSolder
SW4: SW_SPST; SW_Push_SPST_NO_Alps_SKRK
SWRESET1: SW_SPST; SW_Push_SPST_NO_Alps_SKRK
UESD1: USBLC6-2SC6; SOT-23-6
UFlashMem1: W25Q16JVSS; SOIC-8_5.3x5.3mm_P1.27mm
ULDO1: NCP1117-3.3_SOT223; SOT-223-3_TabPin2
URP2040: RP2040; QFN-56-1EP_7x7mm_P0.4mm_EP3.2x3.2mm
YCrystalOscillator1: ABM8-272-T3; XTAL_ABM8-272-T3; PARTREV 07-29-20

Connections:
+1V1: C106.1, C107.1, C108.1, URP2040.23 (DVDD), URP2040.45 (VREG_VOUT), URP2040.50 (DVDD)
+3V3: C16.1, C104.1, C105.1, C109.1, C110.1, C111.1, C112.1, C113.1, C114.1, C115.1, C117.1, FB1.1, R23.1, R24.1, UFlashMem1.8 (VCC), ULDO1.3 (VI), URP2040.1 (IOVDD), URP2040.10 (IOVDD), URP2040.22 (IOVDD), URP2040.33 (IOVDD), URP2040.42 (IOVDD), URP2040.44 (VREG_IN), URP2040.48 (USB_VDD), URP2040.49 (IOVDD); also elsewhere on the board
+6V5: D101.2 (A); also elsewhere on the board
/RP2040/QSPI_SCLK: UFlashMem1.6 (CLK), URP2040.53 (QSPI_SD0)
/RP2040/QSPI_SD0: UFlashMem1.5 (DI/IO_{0}), URP2040.55 (QSPI_SD1)
/RP2040/QSPI_SD1: UFlashMem1.2 (DO/IO_{1}), URP2040.54 (QSPI_SD2)
/RP2040/QSPI_SD2: UFlashMem1.3 (~WP/IO_{2}), URP2040.51 (QSPI_SD3)
/RP2040/QSPI_SD3: UFlashMem1.7 (~HOLD/~RESET/IO_{3}), URP2040.52 (QSPI_SCLK)
/RP2040/QSPI_SS: R101.2, UFlashMem1.1 (~CS), URP2040.56 (QSPI_SS)
/RP2040/USB_D1+: RDplus1.1, UESD1.6 (I/O1)
/RP2040/USB_D1-: RDminus1.1, UESD1.4 (I/O2)
/RP2040/USB_D2+: RDplus1.2, URP2040.47 (USB_DP)
/RP2040/USB_D2-: RDminus1.2, URP2040.46 (USB_DM)
/RP2040/USB_D+: JUSBC1.A6 (D+), JUSBC1.B6 (D+), UESD1.1 (I/O1)
/RP2040/USB_D-: JUSBC1.A7 (D-), JUSBC1.B7 (D-), UESD1.3 (I/O2)
/RP2040/XIN: C102.2, URP2040.20 (XIN), YCrystalOscillator1.1
/RP2040/XOUT: R105.2, URP2040.21 (XOUT)
ADC0: URP2040.38 (GPIO26_ADC0); also elsewhere on the board
ADC1: URP2040.39 (GPIO27_ADC1); also elsewhere on the board
ADC2: URP2040.40 (GPIO28_ADC2); also elsewhere on the board
ADC3: URP2040.41 (GPIO29_ADC3); also elsewhere on the board
ENC0A: URP2040.8 (GPIO6); also elsewhere on the board
ENC0B: URP2040.9 (GPIO7); also elsewhere on the board
ENC1A: URP2040.11 (GPIO8); also elsewhere on the board
ENC1B: URP2040.12 (GPIO9); also elsewhere on the board
ENC2A: URP2040.13 (GPIO10); also elsewhere on the board
ENC2B: URP2040.14 (GPIO11); also elsewhere on the board
EXT/SD: URP2040.32 (GPIO21); also elsewhere on the board
GND: C16.2, C101.2, C102.1, C103.1, C104.2, C105.2, C106.2, C107.2, C108.2, C109.2, C110.2, C111.2, C112.2, C113.2, C114.2, C115.2, C117.2, C120.1, JUSBC1.A1 (GND), JUSBC1.A12 (GND), JUSBC1.B1 (GND), JUSBC1.B12 (GND), JUSBC1.S1 (SHIELD), R109.2, RUSB1.2, SW4.1 (A), SWRESET1.2 (B), UESD1.2 (GND), UFlashMem1.4 (GND), ULDO1.1 (GND), URP2040.19 (TESTEN), URP2040.57 (GND), YCrystalOscillator1.2 (GND), YCrystalOscillator1.4 (GND); also elsewhere on the board
GPIO20: URP2040.31 (GPIO20); also elsewhere on the board
GPIO24: URP2040.36 (GPIO24); also elsewhere on the board
GPIO25: URP2040.37 (GPIO25); also elsewhere on the board
INT: URP2040.34 (GPIO22); also elsewhere on the board
M0_DIR: URP2040.17 (GPIO14); also elsewhere on the board
M0_PWM: URP2040.4 (GPIO2); also elsewhere on the board
M1_DIR: URP2040.18 (GPIO15); also elsewhere on the board
M1_PWM: URP2040.5 (GPIO3); also elsewhere on the board
M2_DIR: URP2040.16 (GPIO13); also elsewhere on the board
M2_PWM: URP2040.15 (GPIO12); also elsewhere on the board
MUX_S0: URP2040.35 (GPIO23); also elsewhere on the board
unnamed: C103.2, R105.1, YCrystalOscillator1.3
unnamed: C101.1, D101.1 (K), D102.1 (K), ULDO1.2 (VO)
unnamed: JUSBC1.A5 (CC1), RUSB1.1
unnamed: JUSBC1.B5 (CC2), R109.1
unnamed: R101.1, SW4.2 (B)
unnamed: C120.2, FB1.2, URP2040.43 (ADC_AVDD)
RUN: SWRESET1.1 (A), URP2040.26 (RUN)
SCL: R23.2, URP2040.7 (GPIO5); also elsewhere on the board
SDA: R24.2, URP2040.6 (GPIO4); also elsewhere on the board
SPIO_CLK: URP2040.29 (GPIO18); also elsewhere on the board
SPIO_CS: URP2040.28 (GPIO17); also elsewhere on the board
SPIO_MISO: URP2040.27 (GPIO16); also elsewhere on the board
SPIO_MOSI: URP2040.30 (GPIO19); also elsewhere on the board
SWCLK: URP2040.24 (SWCLK); also elsewhere on the board
SWDIO: URP2040.25 (SWD); also elsewhere on the board
UART0_RX: URP2040.2 (GPIO0); also elsewhere on the board
UART0_TX: URP2040.3 (GPIO1); also elsewhere on the board
VBUS: D102.2 (A), JUSBC1.A4 (VBUS), JUSBC1.A9 (VBUS), JUSBC1.B4 (VBUS), JUSBC1.B9 (VBUS), UESD1.5 (VBUS)

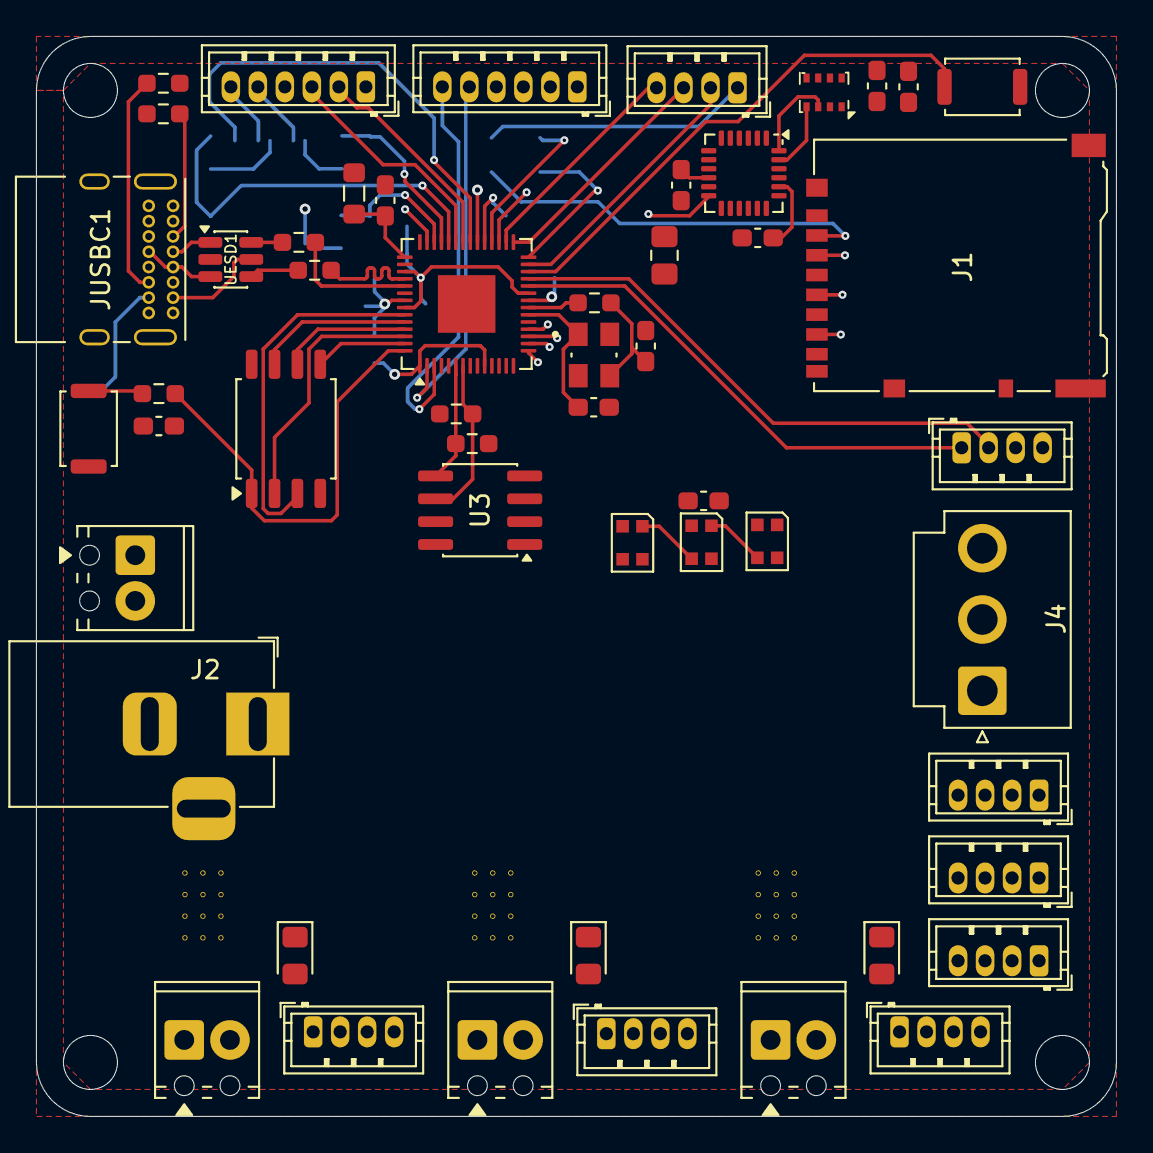
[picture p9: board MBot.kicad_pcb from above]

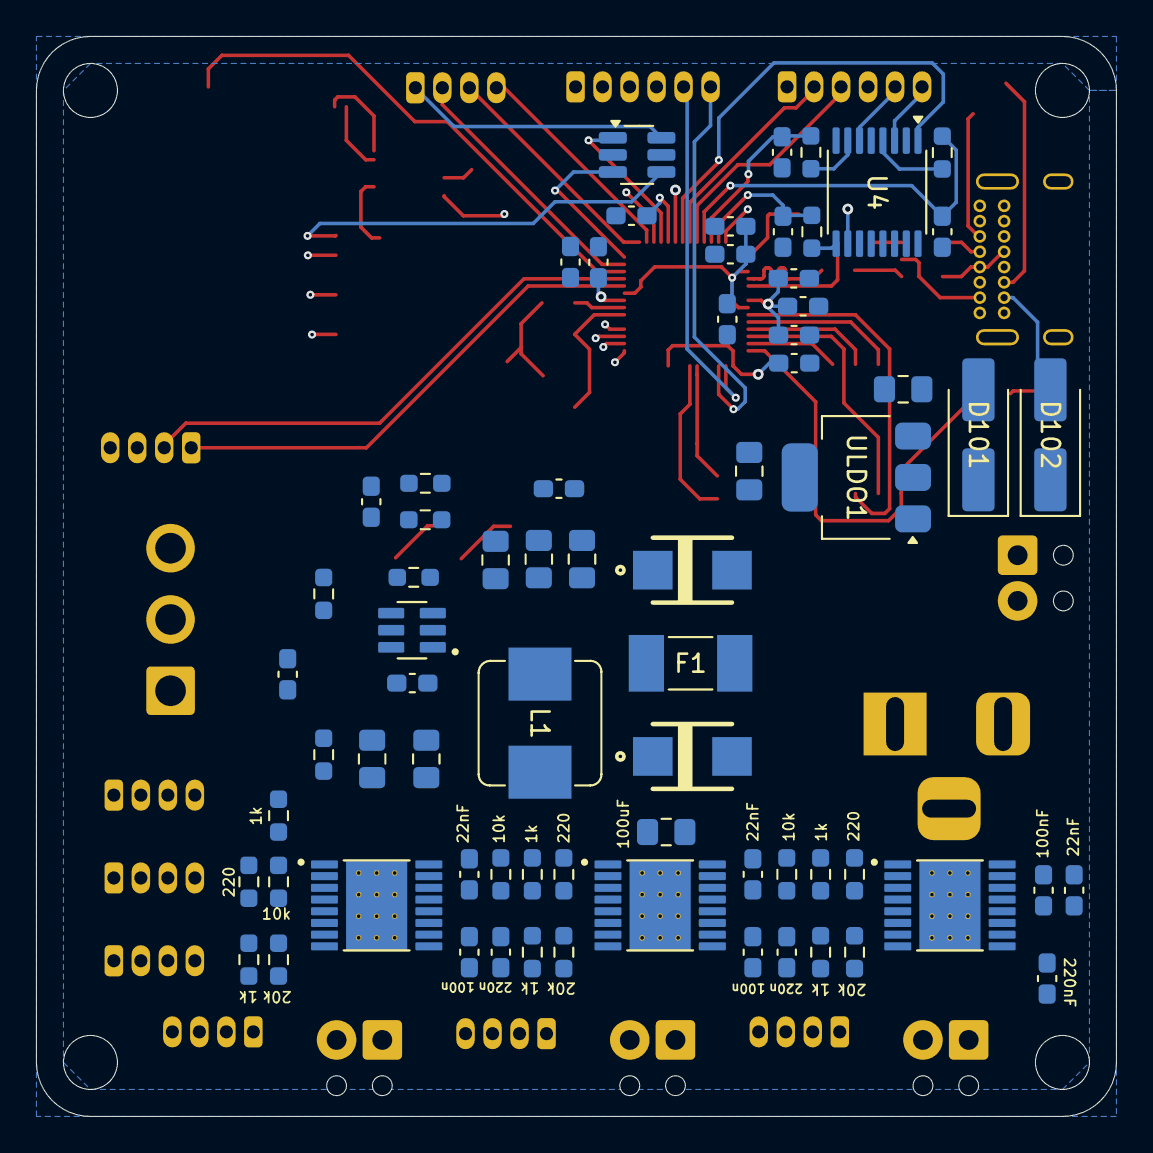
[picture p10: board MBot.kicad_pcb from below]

Board: 4 copper layers, 60.0 x 60.0 mm, 122 parts (70 on the bottom side), 109 nets.

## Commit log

2025-12-30 Initial Upload
    [CurrentSensing.kicad_sch, ExternalPorts.kicad_sch, FRAM.kicad_sch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]
2025-12-30 Add README for Astra Robotics Controller
    Added detailed documentation for the Astra Robotics Controller, including system architecture, technical specifications, pin configuration, power system, safety features, fabrication notes, and getti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
2025-12-30 Add schematic viewing instructions to README
    Added instructions to view the schematic in KiCad.
